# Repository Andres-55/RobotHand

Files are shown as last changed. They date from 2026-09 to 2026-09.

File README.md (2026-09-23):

# Robot Hand

## Overview

I originally started this project with the idea of controlling a robot arm by mirroring the movement of my own arm. This was my first hands-on project, so I made many mistakes along the way, which helped me learn a lot. 

The final project uses a laptop camera to track my hand and control five servo motors on a robotic hand. The camera detects my fingers using Python, OpenCV, and MediaPipe. The calculated finger positions are sent to an Arduino through serial communication, which controls the servos.

https://github.com/user-attachments/assets/ec4b08c5-9e10-4184-8056-761c9ff1205a

## How It Works

The laptop camera captures my hand and sends the frames to the Python program. MediaPipe detects the hand and shows different  points for the fingers and wrist.

For each finger, I calculate the distance between the fingertip and the base of the finger. I then compare that distance to a reference distance near the wrist. This creates a ratio that stays more consistent when my hand moves closer to or farther from the camera.

The ratio is mapped to a servo angle between 0 and 180 degrees. Python then sends the five angles to the Arduino through serial communication.

The Arduino receives the values and moves the five servos to match the movement of my fingers.

## Main Parts

* Arduino Uno Rev 3
* [5 Servo Motors](https://www.amazon.com/gp/product/B0DTPC25YB/ref=ewc_pr_img_2?smid=A2YXT9869S9BVI&psc=1)
* [5V 20A Switching Power Supply](https://www.amazon.com/Aclorol-Switching-Universal-Transformer-Converter/dp/B07KC55TJF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)
* [Terminal block](https://www.amazon.com/Terminal-Circuits-200v-450v-Terminals-Connectors/dp/B09VSWRQ66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)
* [Capacitors](https://www.amazon.com/Pieces-1000uf-Capacitor-Aluminum-Electrolytic/dp/B07R432MR2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)
* [Fishing wire](https://www.amazon.com/Fishing-Monofilament-Invisible-Decorations-Suitable/dp/B09N72VZGW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)
* [18 Gauge Wire](https://www.amazon.com/Automotive-Flexible-Security-Stranded-Electrical/dp/B0CKR35SX5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)
* Power Cord
* Cardboard
* Hot glue
* Rubber Bands
* Laptop webcam
* 3D-printed servo mounts
* Python with OpenCV and MediaPipe

## Starting the Project

I used OpenCV to access the camera on my laptop and MediaPipe to detect my hand.

I first got it to work with one finger. I calculated the distance between the fingertip and the base of the finger, then mapped that distance to a servo angle.

This worked, but there was a major problem. The finger would only move correctly when my hand was at a specific distance from the camera.

I first tried including the Z-axis when calculating the distance, but this did not work. Then I tried adding a reference point near the wrist.

I calculated both the finger distance and the reference distance, then divided them to create a ratio. Since the reference distance changes with the size of the hand in the camera, the ratio kept the distance constant as the hand moves around.

## Power Problems

Once I started controlling multiple servos, I found a problem. The Arduino by itself could not provide enough current for more than two motors at the same time.

To be safe, I switched to a 5V 20A switching power supply, but it would also be fine with 15A. I also needed a terminal block and capacitors to make the wiring easier to manage and keep up wth power spikes.

Here is how I wired my whole project:
Cut the end of the power cord(without prongs) and connect it to the power supply. 
Connect the power supply to the terminal block so that everything is in series.
Connect each motor to a positive and negative section on the terminal block and connect the signal wire directly to the Arduino. 
Just remember which motor each pin is connected to so it matches the Arduino code(ex: If the thumb motor is connected to pin 5, then attach the corresponding servo to pin 5)
Connect the ground pin on the Arduino to a ground section on the terminal block
I also added 2 capacitors to the setup to handle any power spikes when operating

<p align="center">
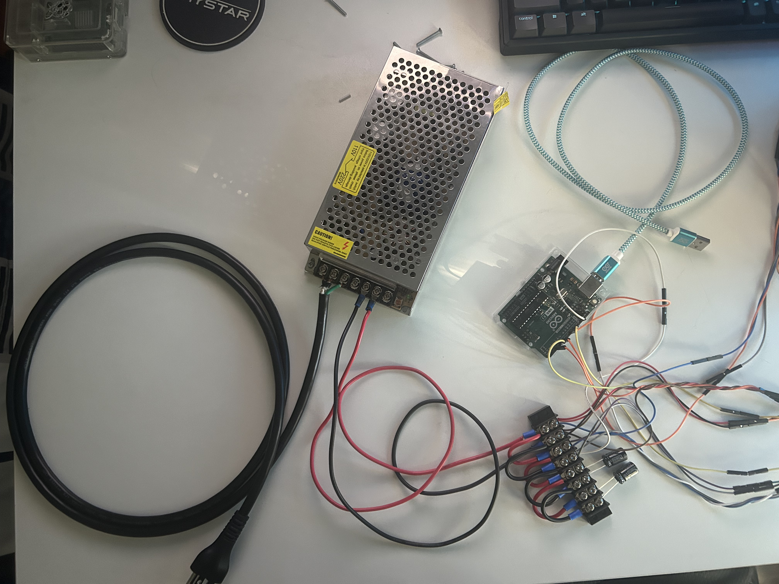
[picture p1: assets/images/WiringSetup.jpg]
Wiring Setup
  
</p>

## Building the Hand

I built the hand using cardboard and hot glue. I used this [YouTube video](https://www.youtube.com/watch?v=GTH_Tzg1DmA&t=174s) to make the fingers, but I needed to change the palm and forearm to accommodate the motors.

I made the top of the palm detachable so I could easily add the wire or change anything if needed. I also made the wrist into a pentagon shape so each side could hold a motor, with one side being detachable to easily work on the motors.

<p align="center">
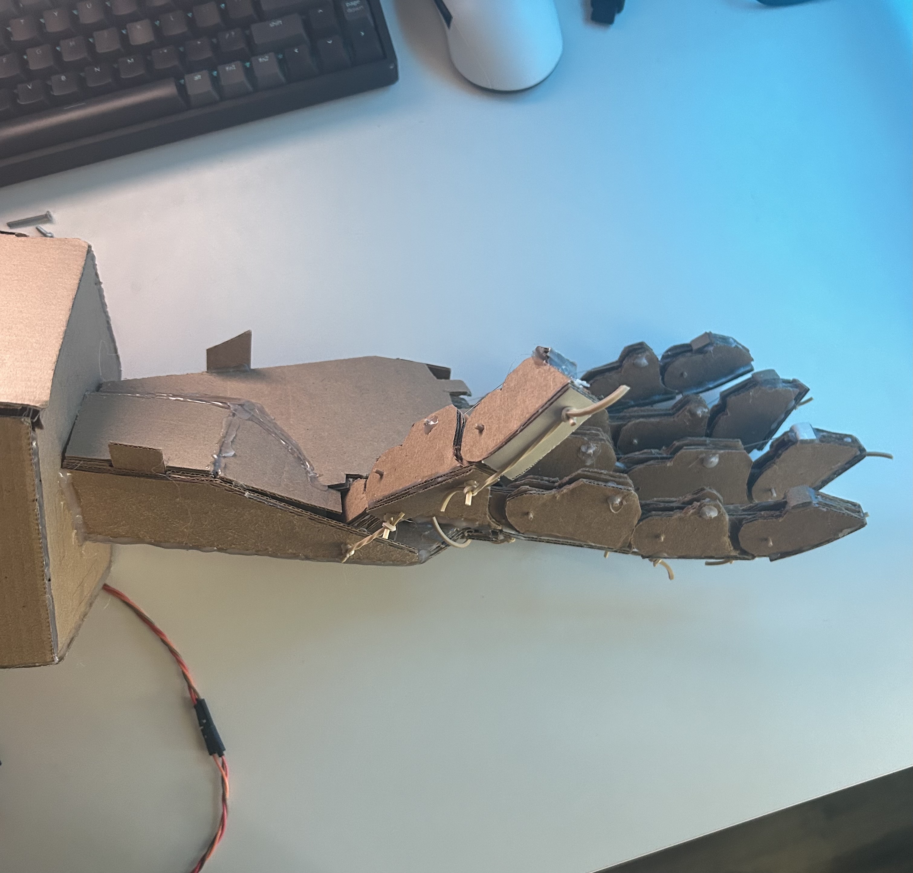
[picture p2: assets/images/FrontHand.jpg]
FrontHand
   
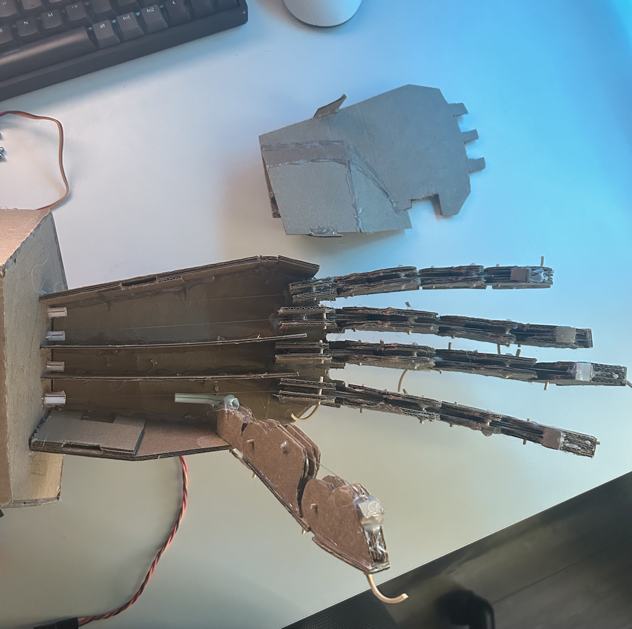
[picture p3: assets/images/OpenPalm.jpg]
OpenPalm
  
</p>

<p align="center">
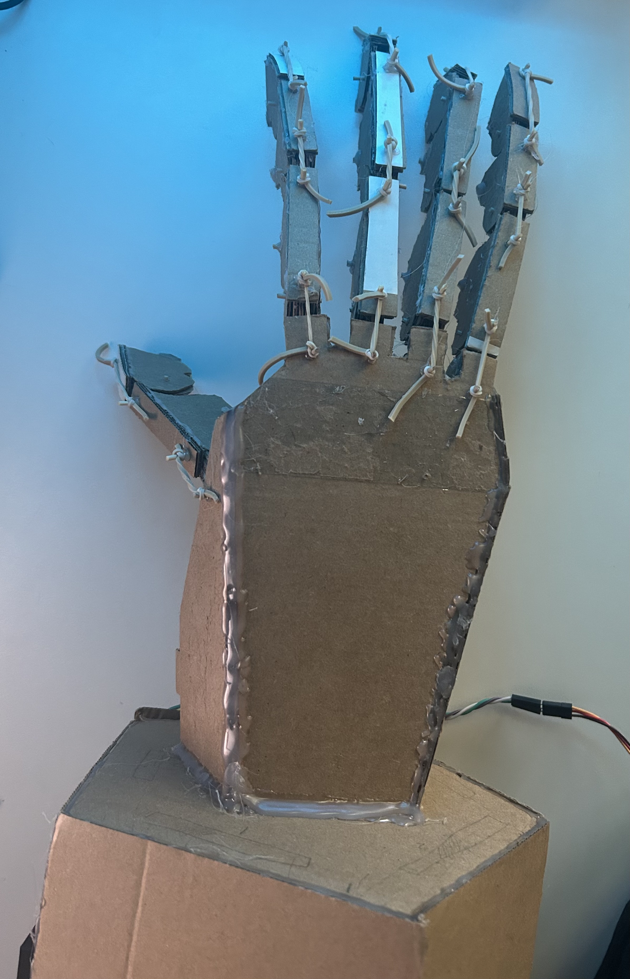
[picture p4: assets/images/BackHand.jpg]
BackHand
  
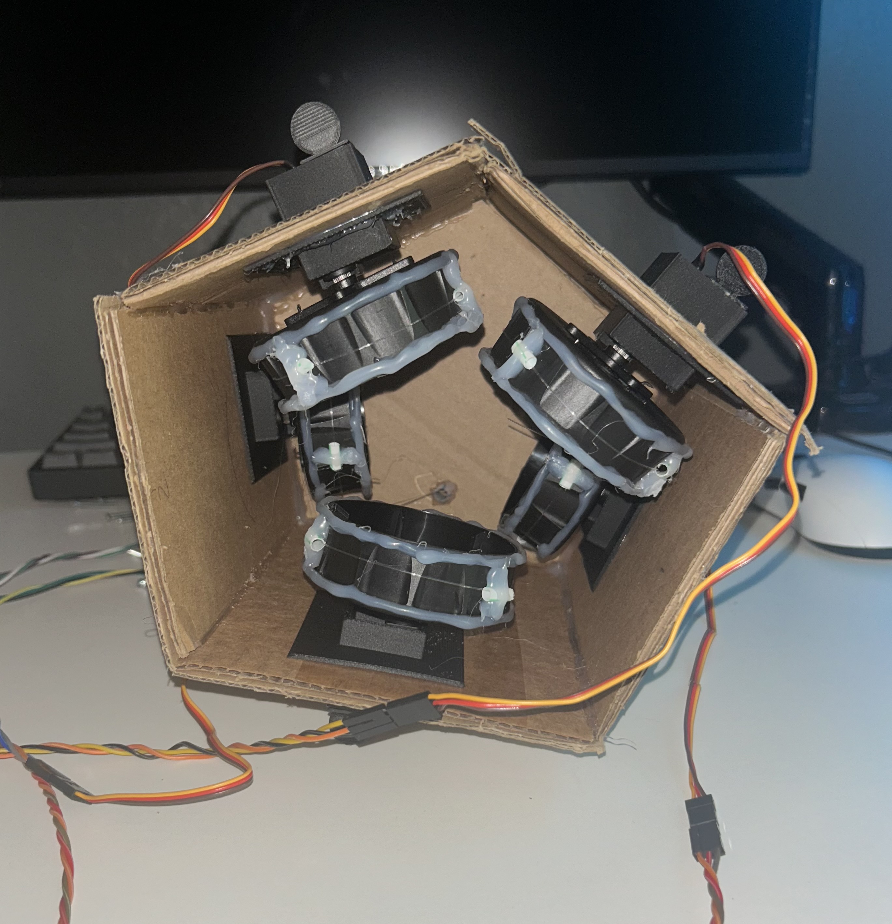
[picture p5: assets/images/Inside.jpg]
Inside
  
</p>

<p align="center">
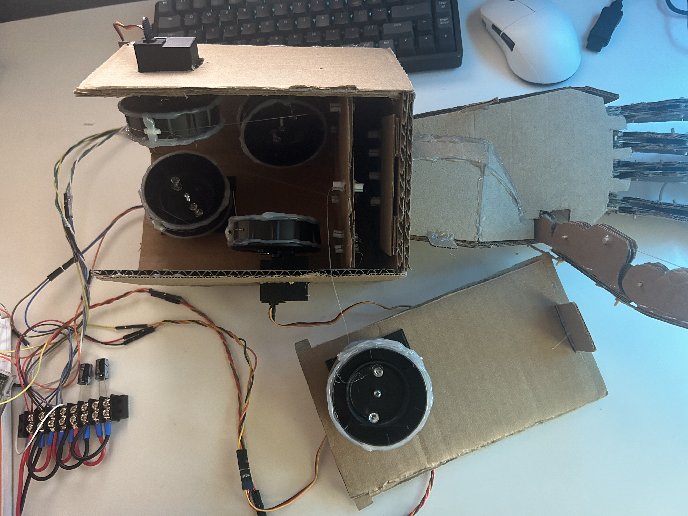
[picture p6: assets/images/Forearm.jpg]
Forearm
  
</p>

## Solving the Servo Problems

The first problem with the servo motors was that the arms were too short to pull the fingers far enough.

At the time, I did not have a 3D printer, so I had to get creative and used a large bottle cap. I attached the bottle cap to the servo arm and used it as a larger spool for the fishing line. I also added hot glue around the cap to keep the line from slipping off.

This gave the servo enough pulling distance to fully curl the fingers.

<p align="center">
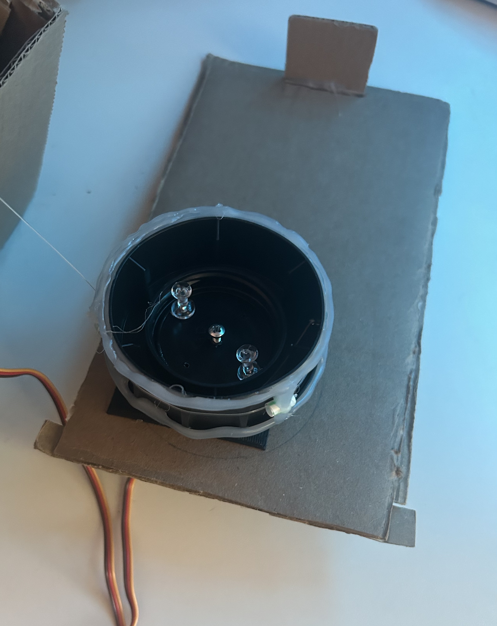
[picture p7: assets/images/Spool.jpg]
Spool
  
</p>

I then added rubber bands to pull the fingers back into an open position. This created another problem because the original servos were not strong enough to pull against the rubber bands.

I eventually replaced them with stronger 5V servos that were about three times as strong. The new servos were strong enough to curl the fingers, but they kept pulling themselves out of the hole in the cardboard.

By this point, I had a 3D printer, so I designed and printed custom servo mounts. The mounts held the servos in place while still making it easy to add or remove the motors.

<p align="center">
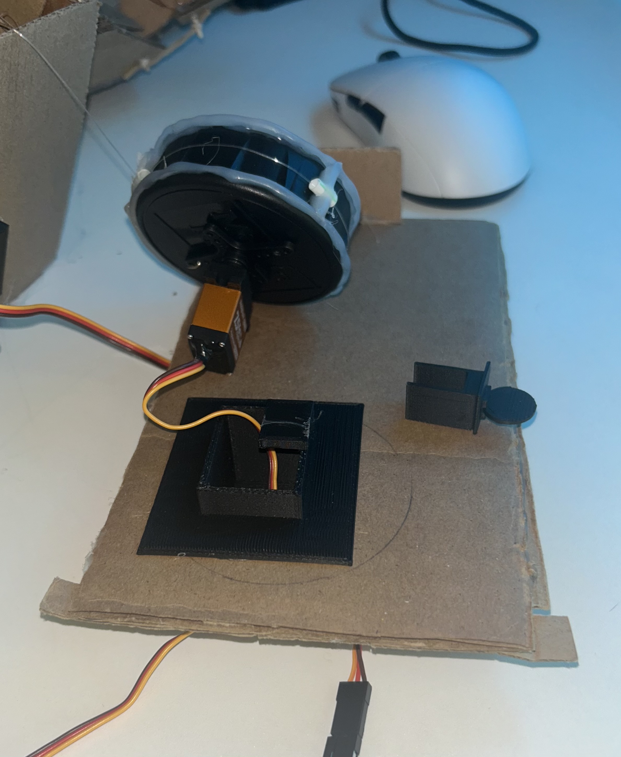
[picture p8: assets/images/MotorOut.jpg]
MotorOut
  
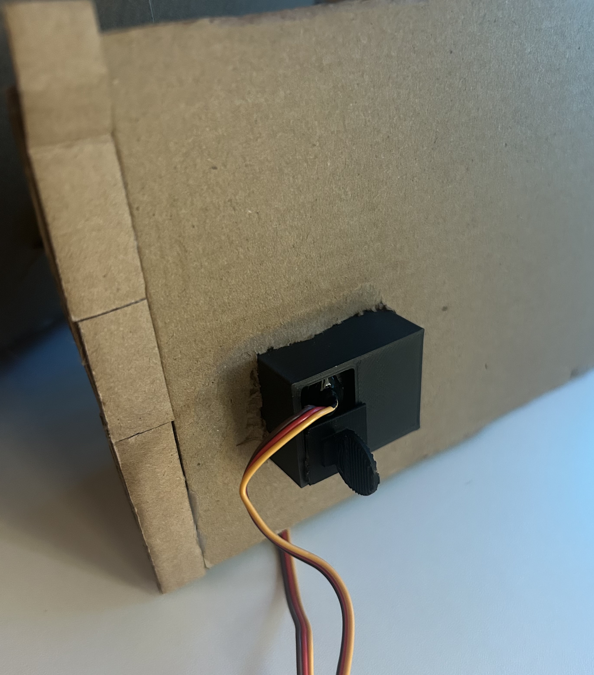
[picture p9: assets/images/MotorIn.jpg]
MotorIn
  
</p>

Here are the [STL files](MotorMountObjects) for the motor mounts

## Final Result

The final hand can track all five fingers using a laptop camera and move the corresponding servos in real time.

The hand is built mostly from cardboard, with a couple of 3D-printed parts for the motor mounts. Some parts are detachable, which allows you to work on any part without having to disassemble anything.

<p align="center">
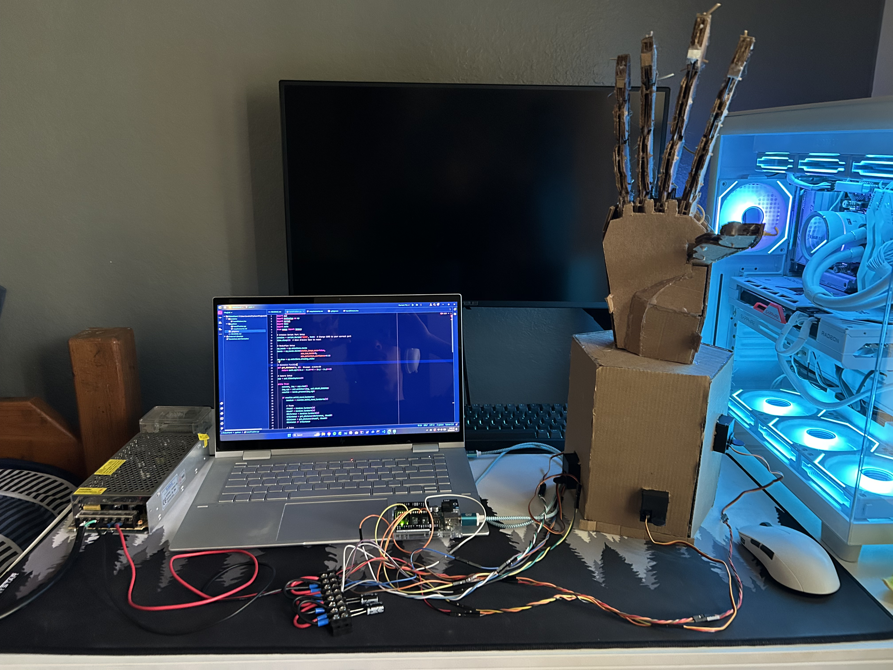
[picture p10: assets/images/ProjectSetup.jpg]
Project Setup
  
</p>

## What I Learned

While this project presented a lot of new challenges to overcome, it has inspired me to want to work on other projects in the future. I had to learn about power supplies, wiring, servos, mechanical designs, Arduino programming, computer vision, and CAD.

One of the biggest things I learned was that the initial plan can change a lot. I actually started with EMG sensors, but the setup became too complicated and expensive, so I changed the project to use computer vision. I also had to redesign parts many times when the motors, power system, or cardboard structure did not work as expected.

I learned that mechanical problems can make or break the entire project. A small change like using a bottle cap as a spool on the motor allowed the fingers to curl all the way.

Most of the project was built by testing an idea, checking if it would work with the other parts, and changing the design until it worked. This process taught me more than simply following a project tutorial from beginning to end.

## Future Improvements

While the project works as I expected, there are still a few things I would like to improve:

* 3D print the fingers to reduce friction between the moving parts
* Make the detachable forearm section more stable
* 3D print the spool to make it lighter and be 1 single piece
* Make the thumb curl as fast as the other fingers

## Software

The Python program uses:

* OpenCV
* MediaPipe
* NumPy
* PySerial

## How to Set Up and Run the Program

### 1. Clone the Repository 

* Click on the green "Code" button at the top right and copy the URL
* Open PyCharm and go to File -> Project from Version Control
* Make sure you are in the Repository URL section
* Then paste the URL into the box next to "URL"
* Choose where you want to save it and click "Clone"

### 2. Download Python
* Make sure that you have Python installed on your computer
* You can check by going to the bottom left and clicking on the terminal button
* Then type:
  ```
  python --version
  ```
* into the terminal, and you should get a version number
* If not, you can download it from python.org

### 3. Create a Virtual Environment

* In PyCharm, go to:
* File -> settings -> Project -> Python Interpreter
* Click "Add Interpreter" and select "Add Local Interpreter"
* Choose Virtualenv for the type
* For Base Python, choose Python 3.9.13
* If it is not available, install Python 3.9.13 separately and select it as the Base Python
* Click "Apply" and "Ok"
* Open the PyCharm terminal and check that there is "(.venv)" at the beginning of the line
* (You might need to open a new terminal)

### 4. Install Libraries
* Using the terminal, go to the Python folder(make sure you see "(.venv)" at the beginning of the line):
```
cd python
```
* Then install the required libraries:
```
python -m pip install -r requirements.txt
```

### 5. Connect the Arduino

* Download the IDE from [here](https://docs.arduino.cc/software/ide/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.)
* Open the arduino/handMotors.ino file or copy and paste the code into a new file
* Connect the Arduino to your computer with a USB cable
* Select the correct Arduino board and COM port in the drop-down list in the top left
* Upload the code to the Arduino by clicking on the right arrow button in the top left

### 6. Check Serial Port

* In the Arduino IDE, go to Tools -> Port
* and check what port is being used (ex: "COM3")
* If it does not match the code, update the line to match your COM port
```python
arduino = serial.Serial('COM3', 9600)
```

### 7. Run Program

* Make sure the Arduino is still connected to your computer
* Click on the green arrow at the top right to run the program
* The camera should open and track your hand

### Troubleshooting

* If the camera does not open:
* Make sure another application is not already using your camera
* If it does not recognize "solution", make sure mediapipe version 0.10.x is installed by running:
```
python -c "import mediapipe as mp; print(mp.__version__)"
```
* If you have a different version, run: 
```
python -m pip uninstall mediapipe
```
* and confirm it. Then run:
```
python -m pip install mediapipe==0.10.21
```
* The software can be tested without the hand or motors being connected
* Only an Arduino is required to be connected

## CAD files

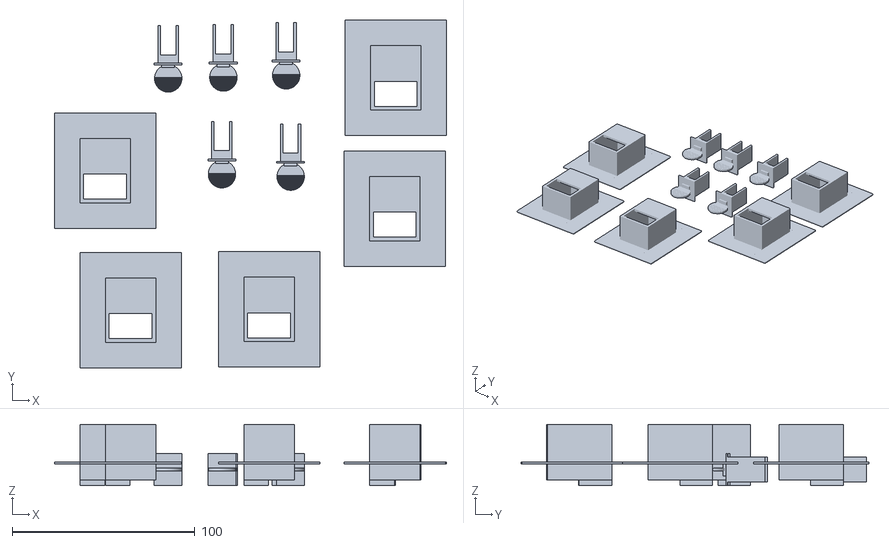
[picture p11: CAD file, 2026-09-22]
MotorMountObjects/MotorMounts.stl
214.5 x 190.4 x 33.6

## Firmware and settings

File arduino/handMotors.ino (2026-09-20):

#include <Servo.h>

Servo s1;
Servo s2;
Servo s3;
Servo s4;
Servo s5;

void setup() {
  Serial.begin(9600);
  s1.attach(3);
  s2.attach(5);
  s3.attach(6);
  s4.attach(9);
  s5.attach(10);
}

void loop() {
  if (Serial.available() >= 5) {
    int angle1 = Serial.parseInt();
    int angle2 = Serial.parseInt();
    int angle3 = Serial.parseInt();
    int angle4 = Serial.parseInt();
    int angle5 = Serial.parseInt();

    // Basic angle range check (0–180) for each
    if (angle1 >= 0 && angle1 <= 180)
    {
      s1.write(angle1);
    }

    if(angle2 >= 0 && angle2 <= 180)
    {
      s2.write(angle2);
    }

    if(angle3 >= 0 && angle3 <= 180)
    {
      s3.write(angle3);
    }

    if(angle4 >= 0 && angle4 <= 180)
    {
      s4.write(angle4);
    }

    if(angle5 >= 0 && angle5 <= 180)
    {
      s5.write(angle5);
    }
  }
}

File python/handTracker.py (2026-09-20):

import cv2
import mediapipe as mp
import serial
import time
import math
from numpy import interp

# Arduino Serial Port Setup
arduino = serial.Serial('COM3', 9600)  # Change COM3 to your correct port
time.sleep(2)  # Give Arduino time to reset

# MediaPipe Setup
mp_hands = mp.solutions.hands
hands = mp_hands.Hands(static_image_mode=False,
                       max_num_hands=1,
                       min_detection_confidence=0.8)
mp_draw = mp.solutions.drawing_utils

# Distance Function
def get_distance(a, b):
    return math.sqrt((a.x - b.x)**2 + (a.y - b.y)**2)

# Camera Setup
cap = cv2.VideoCapture(0)

while True:
    success, img = cap.read()
    img_rgb = cv2.cvtColor(img, cv2.COLOR_BGR2RGB)
    results = hands.process(img_rgb)

    if results.multi_hand_landmarks:
        handLms = results.multi_hand_landmarks[0]

        # Thumb
        thumbB = handLms.landmark[0]
        thumbT = handLms.landmark[4]
        tReference = handLms.landmark[2]
        trDistance = get_distance(tReference, thumbB)
        tDistance = get_distance(thumbT, thumbB)
        tDistance /= trDistance

        # Index
        indexB = handLms.landmark[0]
        indexT = handLms.landmark[8]
        iReference = handLms.landmark[5]
        irDistance = get_distance(iReference, indexB)
        iDistance = get_distance(indexT, indexB)
        iDistance /= irDistance

        # Middle
        middleB = handLms.landmark[0]
        middleT = handLms.landmark[12]
        mReference = handLms.landmark[9]
        mrDistance = get_distance(mReference, middleB)
        mDistance = get_distance(middleT, middleB)
        mDistance /= mrDistance

        # Ring
        ringB = handLms.landmark[0]
        ringT = handLms.landmark[16]
        rReference = handLms.landmark[13]
        rrDistance = get_distance(rReference, ringB)
        rDistance = get_distance(ringT, ringB)
        rDistance /= rrDistance

        # Pinky
        pinkyB = handLms.landmark[0]
        pinkyT = handLms.landmark[20]
        pReference = handLms.landmark[17]
        prDistance = get_distance(pReference, pinkyB)
        pDistance = get_distance(pinkyT, pinkyB)
        pDistance /= prDistance


        # Map distance (adjust if needed)
        # Example: 0.50 (bent) to 1.00 (straight)
        tAngle = int(interp(tDistance, [1.21, 1.73], [180, 0]))
        tAngle = max(0, min(180, tAngle))  # Clamp to safe servo range

        iAngle = int(interp(iDistance, [0.81, 1.78], [180, 0]))
        iAngle = max(0, min(180, iAngle))  # Clamp to safe servo range

        mAngle = int(interp(mDistance, [0.73, 1.87], [180, 0]))
        mAngle = max(0, min(180, mAngle))  # Clamp to safe servo range

        rAngle = int(interp(rDistance, [0.69, 1.90], [180, 0]))
        rAngle = max(0, min(180, rAngle))  # Clamp to safe servo range

        pAngle = int(interp(pDistance, [0.73, 1.75], [180, 0]))
        pAngle = max(0, min(180, pAngle))  # Clamp to safe servo range

        print(f"Distance: {tDistance:.4f}, Angle: {tAngle}  "
              f"Distance: {iDistance:.4f}, Angle: {iAngle}  "
              f"Distance: {mDistance:.4f}, Angle: {mAngle}  "
              f"Distance: {rDistance:.4f}, Angle: {rAngle}  "
              f"Distance: {pDistance:.4f}, Angle: {pAngle}  ")
        try:
            arduino.write(f"{tAngle},{iAngle},{mAngle},{rAngle},{pAngle}\n".encode())
        except:
            print("Serial connection error.")

        mp_draw.draw_landmarks(img, handLms, mp_hands.HAND_CONNECTIONS)

    else:
        # No hand detected: send a safe default
        arduino.write(b"0,0,0,0,0\n")

    cv2.imshow("Index Finger Tracker", img)
    if cv2.waitKey(1) & 0xFF == ord('q'):
        break


cap.release()
cv2.destroyAllWindows()

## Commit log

2026-09-20 Added python and arduino code for project
2026-09-22 Added folder with stl file for the motor mounts
    [MotorMounts.stl]
2026-09-22 Update motor mounts section in README
    Updated README to include a link to STL files for motor mounts.
2026-09-23 Moved the video to the top of the ReadMe
    Switched the demo video with the finished photo
